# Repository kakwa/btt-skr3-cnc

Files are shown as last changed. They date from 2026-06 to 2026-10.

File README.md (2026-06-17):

# btt-skr3-cnc

Reviving a [Yeti Tool SmartBench](https://www.yetitool.com/) CNC router with new hardware and open-source firmware.

This project replaces pretty much all the sketchy eletronics original electronics with an even sketckier setup.

It keeps the original stepper motors, overal frame, and endstops.

## Project Status

* [done] Pi configuration
* [done] Base grblHAL setup
* [done] Wiring/adapter board
* [in-progress] End stops and safety stop configuration
* [in-progress] Proper enclosure for electronics
* [todo] Spindle control (optional)

## Hardware & Software components

| Component | Details |
|---|---|
| Controller board | [BTT SKR 3 EZ](https://github.com/bigtreetech/SKR-3) |
| Stepper drivers | TMC5160 |
| SBC | [BTT Pi](https://github.com/bigtreetech/BTT-Pi) (or RPi > 3) |
| Firmware | [grblHAL](https://github.com/grblHAL/core/blob/master/README.md) |
| UI & gCode Uploader | [gSender](https://sienci.com/gsender/) |
| Motors Setup | X, Y, Z + ganged X2, Y2 |

## Repository Layout

- `docs/` — project documentation (start here); numbered markdown files covering intro, hardware, install, configuration, troubleshooting, and settings
- `ansible/` — Ansible playbook to provision the BTT Pi (roles: avahi, gsender, grblhal-builder, nginx, ...)
- `grblhal/` — grblHAL firmware as a git submodule (STM32 driver)
- `pcbs/` — KiCad PCB designs for the DB25 breakout boards and adapters
- `cad/` — FreeCAD enclosure and mounting parts
- `tests/` — G-code test files
- `misc/` — utility scripts and raw settings dumps

## Documentation

Project documentation is available in [`docs/`](docs/).

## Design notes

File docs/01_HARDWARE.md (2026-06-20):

# BTT SKR 3 Wiring Guide for grblHAL

## Hardware Overview

- **Board:** [BTT SKR 3 EZ](https://github.com/bigtreetech/SKR-3) (STM32H723VG)
- **Drivers:** [TMC5160T Plus](https://global.bttwiki.com/TMC5160TPlus.html) and/or [TMC5160T Pro](https://global.bttwiki.com/TMC5160T%20Pro%20V1.0.html)
- **Axes:** X (ganged), Y (ganged), Z
- **Total Motors:** 5 (X, X2 on E0, Y, Y2 on E1, Z)

---

## Stepper Controller Allocation

* X          -> X1
* Y          -> Y1
* Z          -> Z
* Extruder 0 -> X2 (ganged)
* Extruder 1 -> Y2 (ganged)

## Breakout Boards

The SmartBench design requires splitting the electronics in two: one part on the top/toolhead, the other below the spoilboard,
with both requiring a wire harness to communicate and transmit power.

The original harness was split in two chains:
* 4 conductors for 24V+230V for powering stuff.
* 13 conductors for the logic and endstops (the loom with the VGA connector).

This split is good: it avoids interference from the power wires.
However, the logic side did not have enough conductors (13) for my setup (3 endstops + 2 SPI TMC drivers).
I even doubt it had enough conductors for the original electronics — the step/dir/enable pins of the two bottom/Y TMC drivers were shared and
the SPI lines were not wired, which seems iffy.

After considering the options (CAN bus, VGA, RJ45 cables, all drivers on top), I decided to replace the logic loom with a DB25 cable.
This connector has enough pins, is common, and should be easy to replace if needed.

I also wanted the setup to be fully reversible with the original electronics — no cutting or clamping of endstop and motor cables.

For all these reasons, I designed two breakout PCBs using KiCad:

* [Bottom breakout PCB](../pcbs/breakout_bottom_dsub25/)
* [Top breakout PCB](../pcbs/breakout_top_dsub25/)

The end result looks like this:

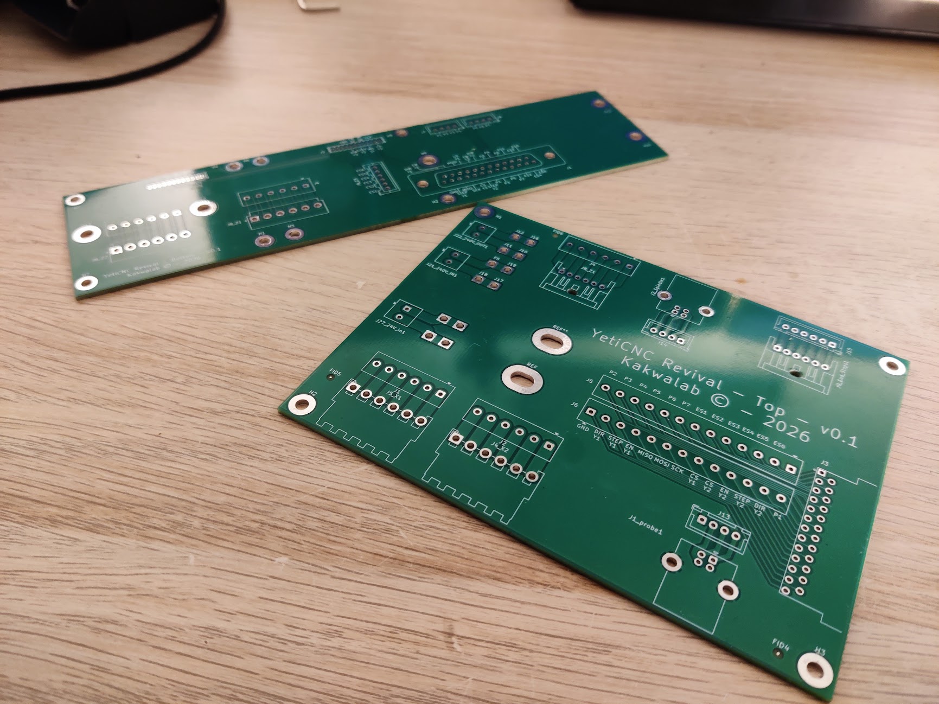
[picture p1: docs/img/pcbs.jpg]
Custom PCBs — top (large) and bottom (small)


These boards interconnect the bottom and top components (via the DB25 cable) and act as adapters between the existing wiring/connectors and what the SKR3 and the TMC5160 drivers expect.
They were also a good opportunity to learn KiCad.

If you are willing to cut some cables, manufacturing these PCBs is not necessary — a pair of DB25 breakout boards with screw terminals can also work:
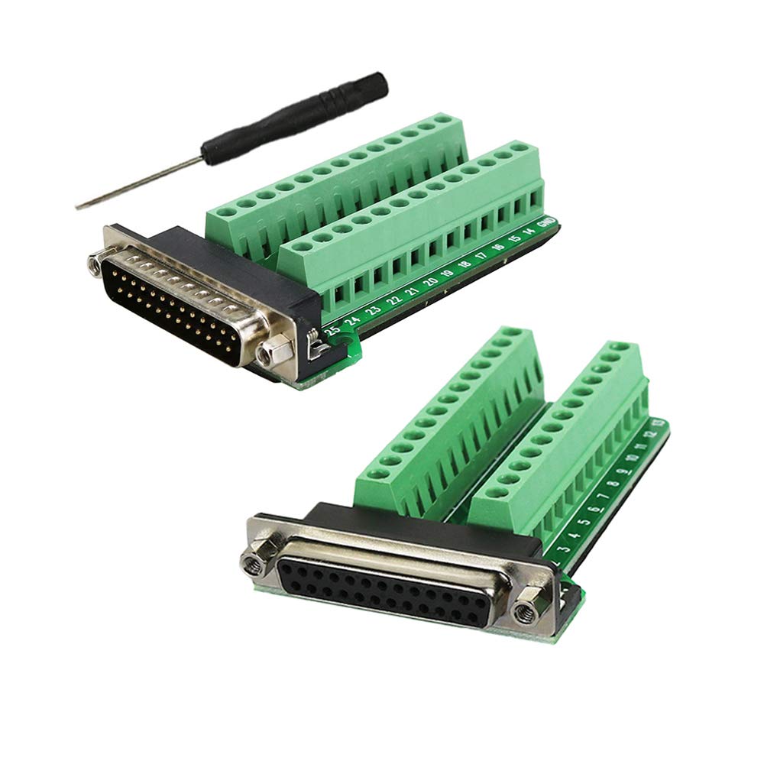
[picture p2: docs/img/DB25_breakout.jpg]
DB25 screw-terminal breakout boards (commercial alternative)


## Stepper Motors & Drivers

Each TMC5160 driver requires at least the following signals routed from the SKR3:

* `STEP`, `DIR`, `EN` — motion control
* `CS` — SPI chip-select (one per driver)
* Shared SPI bus: `MOSI`, `MISO`, `SCK`
* `24V`, `GND` — shared power rails

Here is the non-EZ pinout for reference:

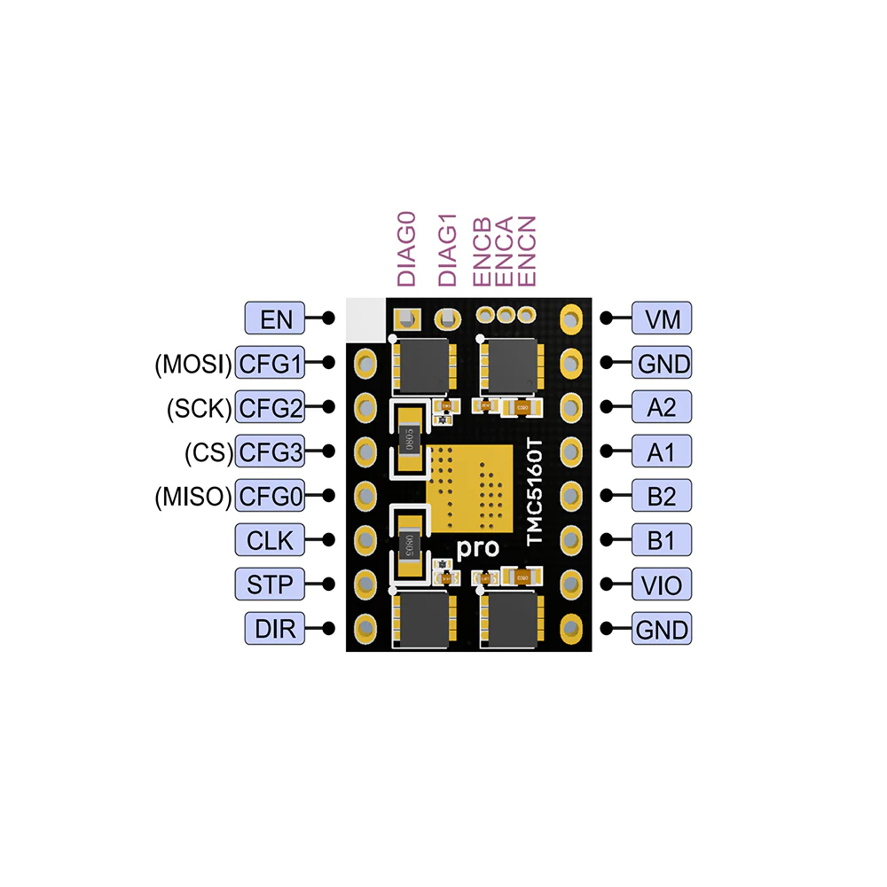
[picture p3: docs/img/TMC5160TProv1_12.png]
Reference Pinout


To connect the Y drivers at the bottom to the SKR 3 board, two adapters are needed.

They can be built easily with a prototype board (strip/breadboard) and some wires:

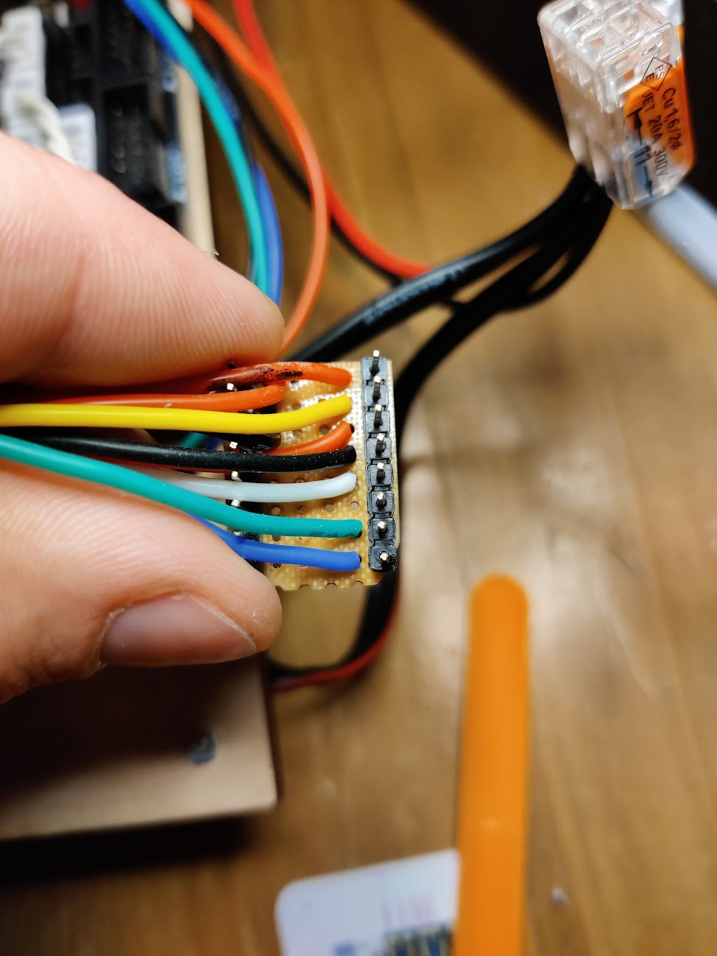
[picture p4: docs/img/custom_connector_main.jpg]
Main motor connector adapter


On the main adapter, everything must be wired:
* SPI bus
* X1-specific pins (DIR, EN, STEP, CS)
* Power & GND

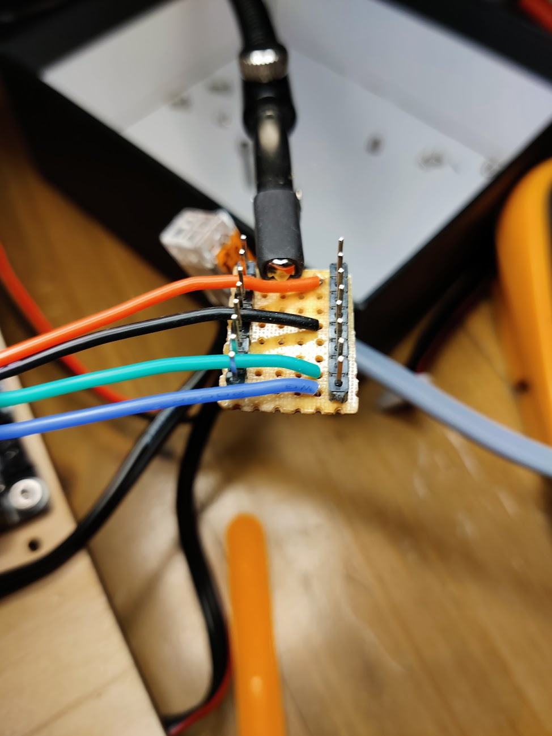
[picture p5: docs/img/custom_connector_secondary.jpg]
Secondary motor connector adapter


On the secondary, only X2-specific signals are needed.

They need to be wired like this:

Stepper Controller Wiring

The end result looks like this:

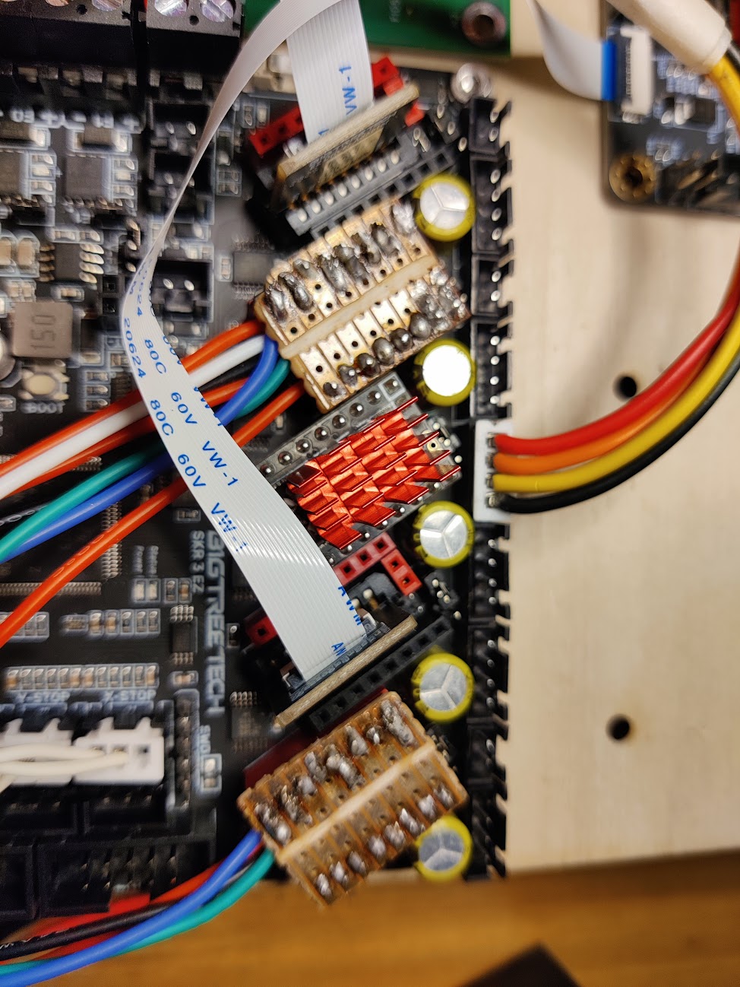
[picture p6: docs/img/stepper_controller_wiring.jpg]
TMC5160 drivers installed


> !Notes
> Most of the more and straight forward usual wiring (PSU, 24V, Stepper loops) is left to the reader.
> However keep in mind the ganded stepper must be mirrored and turning in opposite directions, so if necessary, switch A loop with B loop on X2/Y2.

## Limit Switches, Probe, and Safeties

Port mapping can be found in the [grblHAL board header file for the SKR3](../grblhal/boards/btt_skr_v3.0_map.h).

| Name | GRBLHAL | Pin  | Board label |
|---|---|---|---|
| Z Limit Switch | GPIOC 0 | PC0  | Z- STOP |
| Z Probe | GPIOC 13  | PC13 | Probe |
| Y Limit Switch | GPIOC 3 | PC3  | Y- STOP |
| Y Limit Max Switch | GPIOC 15  | PC15 | PWRDET |
| X Limit Switch | GPIOC 1 | PC1  | X- STOP |
| X Limit Max Switch | GPIOC 2 | PC2  | E0DET |
| Collision Switch/ESTOP | GPIOA 7 | PA7  | EXP2 pin 5  |

Endstop

## Drag Chain

For the DB25 cables (and optionally the power supply for 230V+24V), you can use the drag chain links designed for this build:

* [`chain_link_v2-clip.scad`](../cad/misc/chain_link_v2-clip.scad) — OpenSCAD source for chain links
* [`end1.FCStd`](../cad/misc/end1.FCStd) / [`end2.FCStd`](../cad/misc/end2.FCStd) — FreeCAD models for chain ends

## Spindle

Not handled currently — the spindle runs at fixed speed and is started manually before the job.

## Resulting Jungle

With almost everything connected:

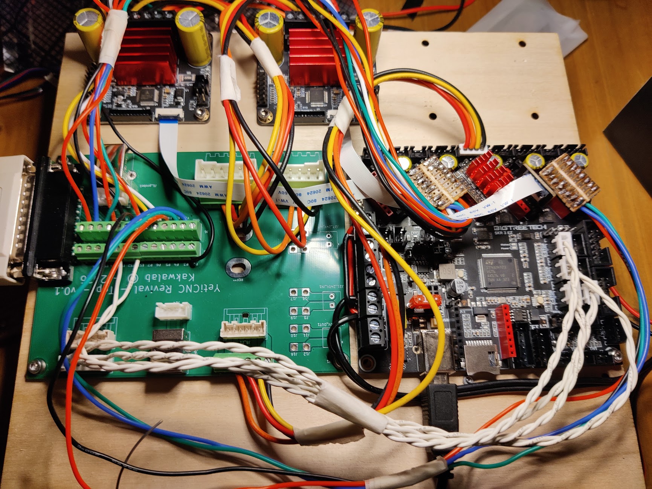
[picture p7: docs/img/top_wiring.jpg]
Top electronics enclosure — top PCB, SKR3, and TMC5160 drivers


The bottom is a bit more manageable:

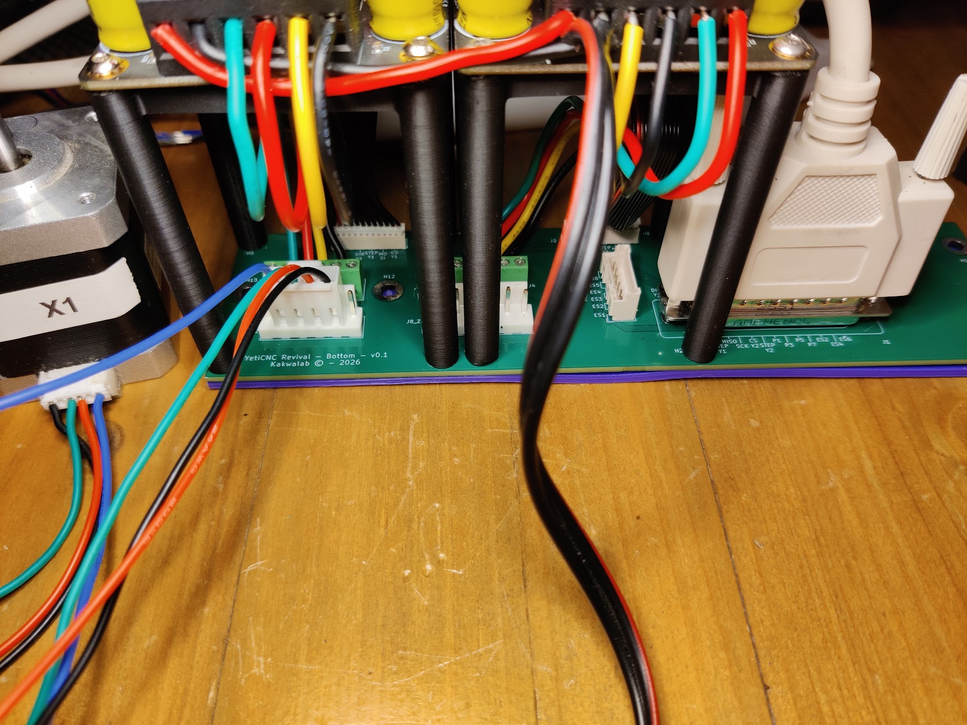
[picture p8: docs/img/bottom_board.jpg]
Bottom breakout board installed, with Y stepper connectors and DB25 cable


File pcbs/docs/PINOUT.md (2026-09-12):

# Pinout

Pin assignment extracted from the schematic. Check strapping/RTC notes before
reassigning pins.

| Refdes | Pin | Name | Net | Notes |
|---|---|---|---|---|
| J1 | 1 | 1 |  | |
| J1 | 2 | 2 |  | |
| J1 | 3 | 3 |  | |
| J1 | 4 | 4 |  | |
| J1 | 5 | 5 |  | |
| J1 | 6 | 6 |  | |
| J1 | 7 | 7 |  | |
| J1 | 8 | 8 |  | |
| J1 | 9 | 9 |  | |
| J1 | 10 | 10 |  | |
| J1 | 11 | 11 |  | |
| J1 | 12 | 12 |  | |
| J1 | 13 | 13 | GND | |
| J1 | 14 | P14 |  | |
| J1 | 15 | P15 |  | |
| J1 | 16 | P16 |  | |
| J1 | 17 | P17 |  | |
| J1 | 18 | P18 |  | |
| J1 | 19 | P19 |  | |
| J1 | 20 | P20 |  | |
| J1 | 21 | P21 |  | |
| J1 | 22 | P22 |  | |
| J1 | 23 | P23 |  | |
| J1 | 24 | P24 |  | |
| J1 | 25 | P25 |  | |
| J2 | 1 | Pin_1 |  | |
| J2 | 2 | Pin_2 |  | |
| J2 | 3 | Pin_3 |  | |
| J2 | 4 | Pin_4 |  | |
| J2 | 5 | Pin_5 |  | |
| J2 | 6 | Pin_6 |  | |
| J2 | 7 | Pin_7 |  | |
| J2 | 8 | Pin_8 |  | |
| J2 | 9 | Pin_9 | GND | |
| J2 | 10 | Pin_10 |  | |
| J2 | 11 | Pin_11 |  | |
| J2 | 12 | Pin_12 | GND | |
| J8_Z1 | 1 | Pin_1 |  | |
| J8_Z1 | 2 | Pin_2 |  | |
| J8_Z1 | 3 | Pin_3 |  | |
| J8_Z1 | 4 | Pin_4 |  | |
| J8_Z1 | 5 | Pin_5 |  | |
| J8_Z1 | 6 | Pin_6 |  | |
| J3 | 1 | Pin_1 |  | |
| J3 | 2 | Pin_2 |  | |
| J3 | 3 | Pin_3 |  | |
| J3 | 4 | Pin_4 |  | |
| J3 | 5 | Pin_5 |  | |
| J3 | 6 | Pin_6 |  | |
| J3 | 7 | Pin_7 |  | |
| J3 | 8 | Pin_8 |  | |
| J3 | 9 | Pin_9 | GND | |
| J3 | 10 | Pin_10 |  | |
| J3 | 11 | Pin_11 |  | |
| J3 | 12 | Pin_12 | GND | |
| J8_Z3 | 1 | Pin_1 |  | |
| J8_Z3 | 2 | Pin_2 |  | |
| J8_Z3 | 3 | Pin_3 |  | |
| J8_Z3 | 4 | Pin_4 |  | |
| J8_Z3 | 5 | Pin_5 |  | |
| J8_Z3 | 6 | Pin_6 |  | |
| J4 | 1 | Pin_1 |  | |
| J4 | 2 | Pin_2 |  | |
| J4 | 3 | Pin_3 |  | |
| J4 | 4 | Pin_4 |  | |
| J4 | 5 | Pin_5 |  | |
| J4 | 6 | Pin_6 |  | |
| J5 | 1 | Pin_1 |  | |
| J5 | 2 | Pin_2 |  | |
| J5 | 3 | Pin_3 |  | |
| J5 | 4 | Pin_4 |  | |
| J5 | 5 | Pin_5 |  | |
| J5 | 6 | Pin_6 |  | |
| J6 | 1 | Pin_1 |  | |
| J6 | 2 | Pin_2 |  | |
| J7 | 1 | Pin_1 |  | |
| J7 | 2 | Pin_2 |  | |
| J7 | 3 | Pin_3 |  | |
| J7 | 4 | Pin_4 |  | |
| J8_Z2 | 1 | Pin_1 |  | |
| J8_Z2 | 2 | Pin_2 |  | |
| J8_Z2 | 3 | Pin_3 |  | |
| J8_Z2 | 4 | Pin_4 |  | |
| J8_Z2 | 5 | Pin_5 |  | |
| J8_Z2 | 6 | Pin_6 |  | |

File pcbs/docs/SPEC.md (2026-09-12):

# bottom_dsub25 — Specification

What the device is, top-level constraints and budgets.

## Budgets

<!-- Add hard budgets here; copperhead treats them as constraints, e.g. -->
<!-- - sleep_current_uA: 25 -->

## Assumptions

<!-- Decisions the agent made without explicit direction are flagged ASSUMED here -->

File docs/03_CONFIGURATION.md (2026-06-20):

# Configuration

## Quick Adjusting

Runtime settings are changed by sending `$N=value` to the board over serial — either via the gSender terminal or `cnc-console`. Each setting is written to flash (NVS) and survives reboots.

See the [grblHAL settings reference](99_SETTINGS.md) for the full list of paramters.

## Making It The Default

Runtime settings persist across power cycles, but a `$RST=*` (factory reset) reverts everything to compile-time defaults. To ensure calibrated values survive a firmware reset:

1. Edit the `grblhal_machine_build_flags` list in `ansible/pi-setup.yml`.
2. Re-run the Ansible playbook with `--tags grblhal` to redeploy `platformio.ini`.
3. Rebuild and reflash the firmware (`skr3-build` then `skr3-flash`).

The corresponding compile-time flags are `-D DEFAULT_X_STEPS_PER_MM=...` etc. They map directly to the `$100`/`$101`/`$102` defaults.

> grblHAL settings are stored in flash. A `$RST=*` is the only way they are lost — a normal reboot preserves them.

## Tuning Points

### Direction

Use `$3` to invert stepper direction for primary axes (bitmask: X=1, Y=2, Z=4).
For ganged axes, `$8` additionally inverts the direction of the second motor (bit 0 = X2, bit 1 = Y2), stacked on top of `$3`.

```bash
$3=0    # no primary axis direction inversion
$8=1    # invert X2 ganged motor only
$8=2    # invert Y2 ganged motor only
$8=3    # invert both ganged motors
```

> The ganged motor (X2/Y2) must turn in the **opposite** direction to its paired primary motor. If the machine racks (X or Y sides move in opposite directions during homing), flip the appropriate bit in `$8`.

### Step <-> Distance Relation

Steps per mm depends on motor full steps/rev (200 for 1.8°), driver microstepping (16 by default), and mechanical pitch.

| Axis | Setting | Nominal (steps/mm) |
|---|---|---|
| X | `$100`  | 80.0 |
| Y | `$101`  | 80.0 |
| Z | `$102`  | 400.0 |
| X2 | `$103`  | 80.0 |
| Y2 | `$104`  | 80.0 |

#### Calibration Protocol

**Step 1 — move a known distance**

Home, then command a large relative move on the axis under test (larger = less measurement error):

> **Warning:** 500 mm is a large move. Jog the axis to roughly the **middle of its travel** before running the move, or it will crash into the far end.

```gcode
$H           ; home all axes
; jog to mid-travel first (e.g. via gSender), then:
G91          ; relative mode
G0 Y140      ; move Y 140 mm  (replace Y with X or Z as needed)
G90          ; back to absolute mode
```

**Step 2 — measure**

Use calipers to measure the actual distance traveled. Note it as `measured`.

**Step 3 — compute and apply**

```
new_steps = current_steps × (commanded / measured)
```

Then set the corrected value:

```gcode
$101=<new_steps>   ; Y axis
```

Repeat from step 1 until measured matches commanded within tolerance.

**Example** — Y commanded 140 mm, measured 210 mm, current `$101=80.0`:

```
new = 80.0 × (140 / 210) = 53.33
```

```gcode
$101=53.33
```

### End Stop

The build flags define the active endstop topology.

**Physical mapping** (from `btt_skr_v3.0_map.h` and build flags):

| Board label | Pin  | grblHAL signal | Purpose |
|---|---|---|---|
| X- STOP | PC1  | `X_LIMIT` | X primary home switch |
| E0DET | PC2  | `M3_LIMIT` | X2 auto-squaring switch |
| Y- STOP | PC3  | `Y_LIMIT` | Y primary home switch |
| PWRDET | PC15 | `M4_LIMIT` | Y2 auto-squaring switch |
| Z- STOP | PC0  | `Z_LIMIT` | Z home switch |
| Probe | PC13 | `PROBE` | Z touch-off / tool length |

**Key homing settings:**

```bash
$22=3     # Enable homing (bit 0) + single-axis $H<X|Y|Z> commands (bit 1)
$23=0     # Homing searches toward negative by default; set bits to reverse per axis
$24=100   # Locate feed rate (mm/min) — slow final approach
$25=1000  # Seek rate (mm/min) — fast initial search
$26=250   # Debounce delay (ms)
$27=5     # Pull-off distance (mm) — must fully clear the switch
$44=4     # Phase 1: home Z first (bitmask: Z=4)
$45=3     # Phase 2: home X and Y together (bitmask: X=1, Y=2)
```

TODO FIXME: currently max and min switch, need to rework that
> Auto-squaring requires **both** limit switches per ganged axis to be functional. If one switch is not triggering, homing will time out or produce a non-zero dual-axis offset in `$170`/`$171`.

### Safety

The collision switch on PA7 (EXP2 pin 5) is active as a **safety door** (`SAFETY_DOOR_ENABLE=1`): triggering it pauses motion and parks the spindle; clearing it allows a resume without a full reset.

Software safety:

```bash
$20=1       # Enable soft limits — requires homing first ($H)
$21=1       # Enable hard limits — alarm on unexpected switch trigger
$130=...    # X max travel (mm) — measure and set
$131=...    # Y max travel (mm)
$132=...    # Z max travel (mm)
```

#### Testing Limit Switches

The `Pn:` field of the `?` status report lists currently triggered inputs. Use this to verify each switch before homing.

1. Open `cnc-console` or the gSender terminal.
2. Send `?` — confirm `Pn:` is empty (no switches active at rest).
3. Manually press each switch one at a time and send `?` again.
4. Confirm the corresponding letter appears in `Pn:`.

| Switch | Board label | Expected `Pn:` letter |
|---|---|---|
| X- STOP | PC1 | `X` |
| Y- STOP | PC3 | `Y` |
| Z- STOP | PC0 | `Z` |
| Probe | PC13 | `P` |

If a switch does not appear, check wiring and the `$5` (invert limit inputs) setting.

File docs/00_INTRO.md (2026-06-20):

# Trying to revive a Yeti Tool SmartBench CNC

## Parts

- **[01_HARDWARE.md](01_HARDWARE.md)** - BTT SKR 3 wiring guide for grblHAL
- **[02_INSTALL.md](02_INSTALL.md)** - Base software setup (Pi, grblHAL build & flash)
- **[03_CONFIGURATION.md](03_CONFIGURATION.md)** - grblHAL configuration
- **[04_TROUBLESHOOTING.md](04_TROUBLESHOOTING.md)** - Troubleshooting and gotchas
- **[90_MISC.md](90_MISC.md)** - Miscellaneous notes
- **[99_SETTINGS.md](99_SETTINGS.md)** - grblHAL settings reference

## Intro

In 2025, I joined a local fablab. If you like building stuff, I would highly recommend it.
These are great places to learn new skills, spend time with really nice people and play
with machines typically out of reach of most.

One of these out-of-reach tools is a SmartBench CNC router by YetiTool. Would love to play with it, but unfortunately, the board burnt out, and it went out of service months before I joined.
To complicate matters, [Yeti Tool went under in 2024](https://find-and-update.company-information.service.gov.uk/company/11310906/insolvency). Not ideal, even if [Trend UK](https://www.trend-eu.com/products/cnc-machines/trend-yeti-cnc-smartbench/trend-yeti-cnc-smartbench) stepped up and started providing spare parts and support.

While I could probably investigate and try fixing the issue, I'm not convinced it's the correct approach:

1. a fix would likely be a fragile bodge just waiting to break again.
2. even if it lasts, it would leave the tool in an unmaintainable state, with no effective software support and partial hardware one.
3. It's less fun

Given I already [built a Voron 0.2](https://www.youtube.com/watch?v=Ej5ZsTKy6t4), it should be easy pizzie lemon squizzy </Dunning-Kruger syndrome>.

## What Are The Options?

Let's limit ourselves to Open Source options, so no [Mach 4](https://www.mach-labs.com/) or similar.

### LinuxCNC + Mesa Hardware

[LinuxCNC](https://linuxcnc.org/) is the gold standard for OSS CNC control: mature, extremely capable, supports virtually any machine topology. But I would not learn that much from it, plus using a PC & Linux for Realtime stuff doesn't seem to fully click.

### FluidNC + ESP32

[FluidNC](https://github.com/bdring/FluidNC) runs on an ESP32 with WiFi built in and YAML-based configuration. It looks really nice and is really promising. The catch is the lack of decent and easily sourceable ESP32 boards. The closest is the [BTT Rodent](https://biqu.equipment/products/bigtreetech-rodent), but it's lacking on the IO and driver department. Plus the drivers are integrated

### grblHAL + STM32

[grblHAL](https://github.com/grblHAL) is GRBL ported to ARM microcontrollers. It keeps GRBL's familiar G-code dialect and adds proper TMC driver support, ganged-axis auto-squaring, and Modbus VFD control. It supports common boards like BTT SKR 3 (STM32H723) I ended up choosing: 5 driver slots, enough GPIO, support of TMC5160.

### Final Choice: grblHAL + BTT SKR 3 + TMC5160 + Pi + gSender

- **BTT SKR 3** (STM32H723VG) running **grblHAL** as the motion controller
- **TMC5160** drivers in UART mode (StallGuard, CoolStep)
- **BTT Pi** running **gSender** as the G-code sender and web UI

For the UI, I picked [gSender](https://sienci.com/gsender/), which is quite nice and has frequent updates.

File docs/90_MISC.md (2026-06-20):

# Misc Pieces of Informations

## Build Work Arounds

**Manual workaround** (if needed):

```bash
# Create symlinks to system toolchain
mkdir -p ~/.platformio/packages/toolchain-gccarmnoneeabi/bin
for f in /usr/bin/arm-none-eabi-*; do
  ln -sf "$f" ~/.platformio/packages/toolchain-gccarmnoneeabi/bin/
done

# Create package.json
cat > ~/.platformio/packages/toolchain-gccarmnoneeabi/package.json << 'EOF'
{
  "name": "toolchain-gccarmnoneeabi",
  "version": "1.70301.190214",
  "description": "System ARM GCC toolchain (symlinked)",
  "keywords": ["toolchain"],
  "license": "GPL-2.0-or-later",
  "system": ["*"]
}
EOF

# Patch platform.json (after first platformio run)
sudo sed -i 's/"version": ">=1.60301.0,<1.80000.0"/"version": "*"/' \
  /root/.platformio/platforms/ststm32/platform.json
```

## Platform.io Packages

For the build, I've created Debian packages for platform.io [here](https://github.com/kakwa/misc-pkg/).

### Manual Flash

#### Step 1: Enter DFU Bootloader Mode

1. **Hold** the BOOT0 button on the SKR3 board
2. **Press and release** the RESET button (while holding BOOT0)
3. **Release** the BOOT0 button

**Verify DFU mode:**
```bash
dfu-util -l
```

You should see:
```
Found DFU: [0483:df11] ver=0200, devnum=X, cfg=1, intf=0, ...
```

#### Step 2: Flash Firmware

```bash
cd /opt/grblhal
dfu-util -a 0 -s 0x08020000 -D .pio/build/btt_skr_30_h723_tmc5160_bl128/firmware.bin
```

**Important:** Use address `0x08020000` (not `0x08000000`) because the SKR3 has a 128KB bootloader.

#### Step 3: Reset Board

Press the **RESET** button on the board to start the firmware.

**Verify it's running:**
```bash
lsusb | grep 0483:5740    # Should show "Virtual COM Port"
ls /dev/ttyACM*           # Serial device (usually /dev/ttyACM0)
```

## Board Configuration

| Setting | Value |
|---|---|
| Board | BTT SKR 3 |
| MCU | STM32H723VG |
| Bootloader | 128KB (factory) |
| Drivers | TMC5160 (UART mode) |
| Flash Address | 0x08020000 |
| PlatformIO Env | `btt_skr_30_h723_tmc5160_bl128` |

## Pi Setup

## Repository Checkout
        
```bash
git clone https://github.com/kakwa/btt-skr3-cnc
cd btt-skr3-cnc/
git submodule update --init --recursive
```     

## Pi Preparation

### SD Card Flashing

Flash the OS to an SD card. Choose one of:

- **Raspberry Pi**: Use Raspberry Pi Imager - https://www.raspberrypi.com/software/
- **BTT Pi** (cheap & 24V, no 5V required): Use Armbian - https://www.armbian.com/bigtreetech-cb1/

### Initial Setup

**Find Pi IP Address via Ethernet (Quick DHCP Server Method):**

If the Pi is not yet on your network, you can set up a quick DHCP server on your local machine to assign it an IP:

```bash
# On your local machine (Linux), install dnsmasq if not already installed
sudo apt install dnsmasq

# List network interfaces and pick your ethernet NIC (often eno1, eth0, enp*s0):
ip addr

# Assign a static address on the link to the Pi (replace eno1 with your interface):
sudo ip addr add 192.168.100.1/24 dev eno1

# Write a minimal dnsmasq config (replace eno1 with your interface):
sudo tee /etc/dnsmasq.conf > /dev/null <<'EOF'
interface=eno1
dhcp-range=192.168.100.50,192.168.100.150,24h
dhcp-option=3
EOF

# Run dnsmasq in foreground
sudo dnsmasq -d -C /etc/dnsmasq.conf

# You should see the IP allocated to the Pi in the logs
# if not, unplug and replug it
```

**Find Pi IP Address via Network Scan:**

```bash
# Scan network for Pi by MAC address prefix
ip neigh | grep -E 'b8:27:eb|dc:a6:32|e4:5f:01|26:a4:ec'
```

**Configure WiFi (if needed):**

```bash
ssh root@<PI_IP>
sudo nmtui
```

**Enable SSH root login:**

```bash
# Enable root login in SSH config
sudo sed -i 's/^#\?PermitRootLogin.*/PermitRootLogin yes/' /etc/ssh/sshd_config
sudo systemctl restart sshd
```

**Setup SSH key for passwordless access:**

```bash
# On your local machine, create SSH key if you don't have one
ssh-keygen
# Copy key to Pi
ssh-copy-id root@<PI_IP>
```

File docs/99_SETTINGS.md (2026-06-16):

# grblHAL Settings Reference

## Table of Contents

- [Motion Control](#motion-control)
- [Spindle Control](#spindle-control)
- [Operational Settings](#operational-settings)
- [Homing & Limits](#homing--limits)
- [Parking](#parking)
- [Axis Configuration](#axis-configuration)
- [Trinamic Driver Settings](#trinamic-driver-settings)
- [Tool Change](#tool-change)
- [I/O Ports](#io-ports)
- [System Settings](#system-settings)

---

## Motion Control

### `$0` — Step pulse time (`µs`, min: 1.5)

Step pulse length in microseconds. Minimum depends on the processor, typically 1–2.5 µs.

> Reduce from the default of 5 when max step rate exceeds ~140 kHz.

---

### `$1` — Step idle delay (`ms`, max: 65535)

Short hold delay when stopping, to let dynamics settle before disabling steppers. Value `255` keeps motors enabled indefinitely.

---

### `$2` — Step pulse invert (`axismask`)

Inverts the step signals (active low).

---

### `$3` — Step direction invert (`axismask`)

Inverts the direction signals (active low).

---

### `$4` — Invert stepper enable output(s) (`axismask`)

Inverts the stepper driver enable signals. Most drivers use active-low enable and require inversion.

> If stepper drivers share the same enable signal, only X is used.

---

### `$29` — Pulse delay (`µs`, max: 20)

Step pulse delay. When set > 0 and < 2, the value is rounded up to 2 µs.

---

### `$37` — Steppers to keep enabled (`axismask`)

Specifies which steppers not to disable when stopped.

---

### `$39` — Enable legacy RT commands (`boolean`)

Enables normal processing of `?`, `!`, and `~` characters when part of a `$`-setting or comment. If disabled, they are added to the input string instead.

---

### `$40` — Limit jog commands (`boolean`)

Limits jog commands to machine workspace for homed axes.

---

### `$680` — Stepper enable delay (`ms`, max: 500)

Delay from stepper enable to first step output. The driver typically adds ~2 ms to this.

---

## Spindle Control

### `$9` — PWM spindle options (`bitfield`)

| Bit | Value | Description |
|-----|---|---|
| 0 | 1 | Enable PWM output |
| 1 | 2 | RPM controls spindle enable signal |
| 2 | 4 | Disable laser mode capability |
| 3 | 8 | Enable ramping |

When *RPM controls spindle enable signal* is set and M3/M4 is active: S0 switches it off, S>0 switches it on.
When *Ramping enable* is set, spin-up/down time is calculated from `$394` and `$539`.

---

### `$16` — Invert spindle signals (`bitfield`)

| Bit | Value | Description |
|-----|---|---|
| 0 | 1 | Spindle enable |
| 1 | 2 | Spindle direction |
| 2 | 4 | PWM |

> **Reboot required** after changing this setting.

---

### `$30` — Maximum spindle speed (`RPM`)

Maximum spindle speed. Can be overridden by spindle plugins.

---

### `$31` — Minimum spindle speed (`RPM`)

Minimum spindle speed. Can be overridden by spindle plugins. When set > 0, `$35` (PWM min value) may need to be adjusted to achieve the configured RPM.

---

### `$32` — Mode of operation

| Value | Mode |
|---|---|
| 0 | Normal |
| 1 | Laser mode |
| 2 | Lathe mode |

- **Laser mode**: consecutive G1/2/3 commands will not halt when spindle speed changes.
- **Lathe mode**: enables G7, G8, G96, and G97.

---

### `$33` — Spindle PWM frequency (`Hz`)

Spindle PWM frequency.

---

### `$34` — Spindle PWM off value (`%`, max: 100)

Spindle PWM off value (duty cycle percentage).

---

### `$35` — Spindle PWM min value (`%`, max: 100)

Spindle PWM minimum value (duty cycle percentage).

---

### `$36` — Spindle PWM max value (`%`, max: 100)

Spindle PWM maximum value (duty cycle percentage).

---

### `$392` — Spindle on delay (`s`, range: 0.5–20)

Delay to allow spindle to spin up after safety door closes or on resume from park.

---

### `$394` — Spindle on delay (`s`, range: 0.5–20)

Delay to allow spindle to spin up. If spindle supports "at speed" detection, this is the timeout before alarm 14 is raised.

---

### `$539` — Spindle off delay (`s`, range: 0.5–20)

Delay to allow spindle to spin down. If spindle supports "at speed" detection, this is the timeout before alarm 14 is raised.

---

## Operational Settings

### `$5` — Invert limit inputs (`axismask`)

Inverts the axis limit input signals.

---

### `$6` — Invert probe inputs (`bitfield`)

| Bit | Value | Description |
|-----|---|---|
| 0 | 1 | Probe |

Inverts the probe input signal(s).

---

### `$8` — Ganged axes direction invert (`bitfield`)

| Bit | Value | Description |
|-----|---|---|
| 0 | 1 | X-Axis |
| 1 | 2 | Y-Axis |

Inverts direction signals for the second motor on ganged axes. Applied in addition to `$3`.

---

### `$10` — Status report options (`bitfield`)

| Bit | Value | Description |
|-----|---|---|
| 0 | 1 | Position in machine coordinate |
| 1 | 2 | Buffer state |
| 2 | 4 | Line numbers |
| 3 | 8 | Feed & speed |
| 4 | 16 | Pin state |
| 5 | 32 | Work coordinate offset |
| 6 | 64 | Overrides |
| 7 | 128 | Probe coordinates |
| 8 | 256 | Buffer sync on WCO change |
| 9 | 512 | Parser state |
| 10  | 1024  | Alarm substatus |
| 11  | 2048  | Run substatus |
| 12  | 4096  | Enable when homing |
| 13  | 8192  | Distance-to-go |

> Parser state is sent separately after the status report and only on changes.
> Run substatus may be used for simple probe protection.

---

### `$11` — Junction deviation (`mm`)

Sets how fast grblHAL travels through consecutive motions. Lower value slows it down.

---

### `$12` — Arc tolerance (`mm`)

Sets the G2/G3 arc tracing accuracy based on radial error.

> Very small values may affect performance.

---

### `$13` — Report in inches (`boolean`)

Enables inch units when returning position and rate values (not settings values).

---

### `$15` — Invert coolant outputs (`bitfield`)

| Bit | Value | Description |
|-----|---|---|
| 0 | 1 | Flood |
| 1 | 2 | Mist |

Inverts coolant and mist signals (active low).

---

### `$18` — Pullup disable limit inputs (`axismask`)

Disables limit signal pullup resistors. Potentially enables pulldown resistors if available.

---

### `$19` — Pullup disable probe inputs (`bitfield`)

| Bit | Value | Description |
|-----|---|---|
| 0 | 1 | Probe |

Disables probe signal pullup resistor(s). Potentially enables pulldown resistor(s) if available.

---

### `$20` — Soft limits enable (`boolean`)

Enables soft limit checks within machine travel. Triggers alarm when exceeded. Requires homing.

---

### `$21` — Hard limits enable (`bitfield`)

| Bit | Value | Description |
|-----|---|---|
| 0 | 1 | Enable |
| 1 | 2 | Strict mode |

When enabled, immediately halts motion and raises an alarm when a limit switch triggers. In strict mode, only homing is possible when a switch is engaged.

---

### `$60` — Restore overrides (`boolean`)

Restores overrides to default values at program end.

---

### `$61` — Safety door options (`bitfield`)

| Bit | Value | Description |
|-----|---|---|
| 1 | 2 | Keep coolant state on door open |

---

### `$62` — Sleep enable (`boolean`)

Enables sleep mode.

---

### `$63` — Feed hold actions (`bitfield`)

| Bit | Value | Description |
|-----|---|---|
| 0 | 1 | Disable laser during hold |
| 1 | 2 | Restore spindle and coolant state on resume |

---

### `$64` — Force init alarm (`boolean`)

Start in alarm mode after a cold reset.

---

### `$65` — Probing options (`bitfield`)

| Bit | Value | Description |
|-----|---|---|
| 0 | 1 | Allow feed override |
| 1 | 2 | Apply soft limits |

Allow feed override during probing and/or limit probing to machine workspace for homed axes.

---

## Homing & Limits

### `$22` — Homing cycle (`bitfield`)

| Bit | Value | Description |
|-----|---|---|
| 0 | 1 | Enable |
| 1 | 2 | Enable single axis commands |
| 2 | 4 | Homing on startup required |
| 3 | 8 | Set machine origin to 0 |
| 4 | 16 | Two switches share one input |
| 5 | 32 | Allow manual |
| 6 | 64 | Override locks |
| 9 | 512 | Per axis feedrates |
| 10  | 1024  | Run startup scripts only on homing completed |

Enables the homing cycle. Requires limit switches on axes to be automatically homed.

- *Enable single axis commands*: allows `$H<axis>` commands for individual axis homing.
- *Allow manual*: axes not auto-homed may be homed manually via `$H` or `$H<axis>`.
- *Override locks*: allows a soft reset to disable "Homing on startup required".

---

### `$23` — Homing direction invert (`axismask`)

Homing searches in the positive direction by default. Set an axis bit to search in the negative direction.

---

### `$24` — Homing locate feed rate (`mm/min`)

Feed rate to slowly engage the limit switch to determine its location accurately.

---

### `$25` — Homing search seek rate (`mm/min`)

Seek rate to quickly find the limit switch before the slower locating phase.

---

### `$26` — Homing switch debounce delay (`ms`)

Short delay between homing cycle phases to let the switch debounce.

---

### `$27` — Homing switch pull-off distance (`mm`)

Retract distance after triggering the switch to disengage it. Homing will fail if the switch isn't cleared.

---

### `$43` — Homing passes (range: 1–128)

Number of homing passes.

---

### `$44` — Axes homing, first phase (`axismask`)

Axes to home in the first phase.

---

### `$45` — Axes homing, second phase (`axismask`)

Axes to home in the second phase.

---

### `$46` — Axes homing, third phase (`axismask`)

Axes to home in the third phase.

---

### `$338` — Trinamic driver (`axismask`)

Enable SPI or UART controlled Trinamic drivers for axes.

---

### `$339` — Sensorless homing (`axismask`)

Enable sensorless homing for axes. Requires SPI or UART controlled Trinamic drivers.

---

## Parking

### `$41` — Parking cycle (`bitfield`)

| Bit | Value | Description |
|-----|---|---|
| 0 | 1 | Enable |
| 1 | 2 | Deactivate upon init |
| 2 | 4 | Enable parking override control|

Enables parking cycle. Requires parking axis to be homed.

---

### `$42` — Parking axis

| Value | Axis |
|---|---|
| 0 | X |
| 1 | Y |
| 2 | Z |

Defines which axis performs the parking motion.

---

### `$56` — Parking pull-out distance (`mm`)

Spindle pull-out and plunge distance (incremental).

---

### `$57` — Parking pull-out rate (`mm/min`)

Spindle pull-out/plunge slow feed rate.

---

### `$58` — Parking target (`mm`, min: -100000)

Parking axis target in machine coordinates `[-max_travel, 0]`.

---

### `$59` — Parking fast rate (`mm/min`)

Parking fast rate to target after pull-out.

---

## Axis Configuration

### Steps per mm

| Setting | Axis |
|---|---|
| `$100`  | X-axis travel resolution (`step/mm`) |
| `$101`  | Y-axis travel resolution (`step/mm`) |
| `$102`  | Z-axis travel resolution (`step/mm`) |

---

### Maximum rate

| Setting | Axis |
|---|---|
| `$110`  | X-axis maximum rate (`mm/min`) |
| `$111`  | Y-axis maximum rate (`mm/min`) |
| `$112`  | Z-axis maximum rate (`mm/min`) |

Used as G0 rapid rate.

---

### Acceleration

| Setting | Axis |
|---|---|
| `$120`  | X-axis acceleration (`mm/sec²`) |
| `$121`  | Y-axis acceleration (`mm/sec²`) |
| `$122`  | Z-axis acceleration (`mm/sec²`) |

Used for motion planning to avoid exceeding motor torque and losing steps.

---

### Maximum travel

| Setting | Axis |
|---|---|
| `$130`  | X-axis maximum travel (`mm`) |
| `$131`  | Y-axis maximum travel (`mm`) |
| `$132`  | Z-axis maximum travel (`mm`) |

Maximum axis travel distance from homing switch. Determines valid machine space for soft limits and homing search distances.

---

### Dual axis offset

| Setting | Axis | Range |
|---|---|---|
| `$170`  | X-axis dual axis offset (`mm`) | -10 – 10  |
| `$171`  | Y-axis dual axis offset (`mm`) | -10 – 10  |
| `$172`  | Z-axis dual axis offset (`mm`) | -10 – 10  |

Offset between sides to compensate for homing switch inaccuracies.

---

## Trinamic Driver Settings

### Motor current (RMS)

| Setting | Axis | Range |
|---|---|---|
| `$140`  | X-axis motor current (`mA`) | 0–3045  |
| `$141`  | Y-axis motor current (`mA`) | 0–3045  |
| `$142`  | Z-axis motor current (`mA`) | 0–3045  |

---

### Microsteps

| Setting | Axis | Range  |
|---|---|---|
| `$150`  | X-axis microsteps (`steps`)  | 1–256  |
| `$151`  | Y-axis microsteps (`steps`)  | 1–256  |
| `$152`  | Z-axis microsteps (`steps`)  | 1–256  |

Microsteps per full step.

---

### Hold current

| Setting | Axis | Range  |
|---|---|---|
| `$210`  | X-axis hold current (`%`)  | 5–100  |
| `$211`  | Y-axis hold current (`%`)  | 5–100  |
| `$212`  | Z-axis hold current (`%`)  | 5–100  |

Motor current at standstill as a percentage of full current.

---

### StallGuard2 — Fast threshold (seek phase)

| Setting | Axis | Range |
|---|---|---|
| `$200`  | X-axis StallGuard2 fast threshold | -64–63  |
| `$201`  | Y-axis StallGuard2 fast threshold | -64–63  |
| `$202`  | Z-axis StallGuard2 fast threshold | -64–63  |

StallGuard threshold for the fast (seek) homing phase.

---

### StallGuard2 — Slow threshold (feed phase)

| Setting | Axis | Range |
|---|---|---|
| `$220`  | X-axis StallGuard2 slow threshold | -64–63  |
| `$221`  | Y-axis StallGuard2 slow threshold | -64–63  |
| `$222`  | Z-axis StallGuard2 slow threshold | -64–63  |

StallGuard threshold for the slow (feed) homing phase.

---

## Tool Change

### `$341` — Tool change mode

| Value | Mode |
|---|---|
| 0 | Normal |
| 1 | Manual touch off |
| 2 | Manual touch off @ G59.3 |
| 3 | Automatic touch off @ G59.3 |
| 4 | Ignore M6 |

- **Normal**: allows jogging for manual touch off; set new position manually.
- **Manual touch off**: rapids to tool change position; use jogging or `$TPW` for touch off.
- **Manual touch off @ G59.3**: rapids to tool change position, then to G59.3 for manual touch off.
- **Automatic touch off @ G59.3**: rapids to tool change position, then to G59.3 for automatic touch off.

---

### `$342` — Tool change probing distance (`mm`)

Maximum probing distance for automatic or `$TPW` touch off.

---

### `$343` — Tool change locate feed rate (`mm/min`)

Feed rate to slowly engage the tool change sensor to determine offset accurately.

---

### `$344` — Tool change search seek rate (`mm/min`)

Seek rate to quickly find the tool change sensor before the slower locating phase.

---

### `$345` — Tool change probe pull-off rate (`mm/min`)

Pull-off rate for the retract move before the slower locating phase.

---

### `$346` — Tool change options (`bitfield`)

| Bit | Value | Description |
|-----|---|---|
| 0 | 1 | Restore position after M6 |
| 1 | 2 | Change tool at G30 |
| 2 | 4 | Fast probe pull off |

- *Restore position after M6*: moves spindle so the tool tip returns to pre-M6 position; otherwise moves only to Z home.
- *Change tool at G30*: rapids to G30 position via tool axis home (requires homed axes).
- *Fast probe pull off*: uses G38.4-style probing for faster touch off.

---

### `$347` — Dual axis length fail (`%`, range: 0–100)

Dual axis length fail threshold as a percentage of axis max travel.

---

### `$348` — Dual axis length fail min (`mm`)

Dual axis length fail minimum distance.

---

### `$349` — Dual axis length fail max (`mm`)

Dual axis length fail maximum distance.

---

## I/O Ports

### `$370` — Invert I/O port inputs (`bitfield`)

| Bit | Value | Description |
|-----|---|---|
| 0 | 1 | Aux 0 |
| 2 | 4 | Aux 2 |
| 3 | 8 | Aux 3 |
| 4 | 16 | Aux 4 |

---

### `$372` — Invert I/O port outputs (`bitfield`)

| Bit | Value | Description |
|-----|---|---|
| 5 | 32 | Aux 5 |
| 6 | 64 | Aux 6 |

---

## System Settings

### `$28` — G73 Retract distance (`mm`)

G73 retract distance for chip-breaking drilling.

---

### `$384` — Disable G92 persistence (`boolean`)

Disables save/restore of G92 offset to non-volatile storage (NVS).

---

### `$393` — Coolant on delay (`s`, range: 0.5–20)

Delay to allow coolant to restart after safety door closes or on resume from park.

---

### `$398` — Planner buffer blocks (range: 30–1000)

Number of blocks in the planner buffer.

> **Reboot required** after changing this setting.

---

### `$481` — Autoreport interval (`ms`, range: 100–1000)

Interval at which the real-time report is sent. Set to `0` to disable.

> **Reboot required** after changing this setting.

---

### `$485` — Keep tool number over reboot (`boolean`)

Retains the current tool number across reboots.

---

### `$486` — Lock coordinate systems (`bitfield`)

| Bit | Value | Description |
|-----|---|---|
| 0 | 1 | G59.1 |
| 1 | 2 | G59.2 |
| 2 | 4 | G59.3 |

Locks coordinate systems against accidental changes.

---

### `$650` — File system options (`bitfield`)

| Bit | Value | Description |
|-----|---|---|
| 0 | 1 | Auto mount SD card |
| 2 | 4 | Hierarchical listing |

Auto mount SD card on startup.

---

### `$673` — Coolant on delay (`s`, range: 0.5–20)

Delay to allow coolant to start (0 or 0.5–20 s).

---

### `$676` — Reset actions (`bitfield`)

| Bit | Value | Description |
|-----|---|---|
| 0 | 1 | Clear homed status if position was lost |
| 1 | 2 | Clear offsets (except G92) |
| 2 | 4 | Clear rapids override |
| 3 | 8 | Clear feed override |

Controls actions taken on a soft reset.

---

### `$700` — Subroutine options (`bitfield`)

| Bit | Value | Description |
|-----|---|---|
| 0 | 1 | Prescan for internal M98 subroutines |

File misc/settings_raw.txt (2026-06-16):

> $HELP Settings

$0: Step pulse time in microseconds, min: 1.5

Step pulse length in microseconds.
Minimum depends on the processor and is typically in the range of 1 - 2.5.

The length has to be reduced from the default value of 5 when max. step rate exceed approximately 140 kHz.

$1: Step idle delay in milliseconds, max: 65535

Sets a short hold delay when stopping to let dynamics settle before disabling steppers. Value 255 keeps motors enabled.

$2: Step pulse invert as axismask

Inverts the step signals (active low).

$3: Step direction invert as axismask

Inverts the direction signals (active low).

$4: Invert stepper enable output(s) as axismask

Inverts the stepper driver enable signals. Most drivers uses active low enable requiring inversion.

NOTE: If the stepper drivers shares the same enable signal only X is used.

$5: Invert limit inputs as axismask

Inverts the axis limit input signals.

$6: Invert probe inputs as bitfield:
    0 - Probe (1)

Inverts the probe input signal(s).

$8: Ganged axes direction invert as bitfield:
    0 - X-Axis (1)
    1 - Y-Axis (2)

Inverts the direction signals for the second motor used for ganged axes.

NOTE: This inversion will be applied in addition to the inversion from setting $3.

$9: PWM spindle options as bitfield where setting bit 0 enables the rest:
    0 - Enable (1)
    1 - RPM controls spindle enable signal (2)
    2 - Disable laser mode capability (4)
    3 - Enable ramping (8)

Enable controls PWM output availability.
When `RPM controls spindle enable signal` is checked and M3 or M4 is active S0 switches it off and S > 0 switches it on.
When 'Ramping enable' is checked spin up and spin down time is calculated from $394 and $539 respectively.

$10: Status report options as bitfield:
    0 - Position in machine coordinate (1)
    1 - Buffer state (2)
    2 - Line numbers (4)
    3 - Feed & speed (8)
    4 - Pin state (16)
    5 - Work coordinate offset (32)
    6 - Overrides (64)
    7 - Probe coordinates (128)
    8 - Buffer sync on WCO change (256)
    9 - Parser state (512)
    10 - Alarm substatus (1024)
    11 - Run substatus (2048)
    12 - Enable when homing (4096)
    13 - Distance-to-go (8192)

Specifies optional data included in status reports and if report is sent when homing.
If Run substatus is enabled it may be used for simple probe protection.

NOTE: Parser state will be sent separately after the status report and only on changes.

$11: Junction deviation in mm

Sets how fast grblHAL travels through consecutive motions. Lower value slows it down.

$12: Arc tolerance in mm

Sets the G2 and G3 arc tracing accuracy based on radial error. Beware: A very small value may effect performance.

$13: Report in inches as boolean

Enables inch units when returning any position and rate value that is not a settings value.

$15: Invert coolant outputs as bitfield:
    0 - Flood (1)
    1 - Mist (2)

Inverts the coolant and mist signals (active low).

$16: Invert spindle signals as bitfield:
    0 - Spindle enable (1)
    1 - Spindle direction (2)
    2 - PWM (4)

Reboot required.

Inverts the spindle on, counterclockwise and PWM signals (active low).

NOTE: A hard reset of the controller is required after changing this setting.

$18: Pullup disable limit inputs as axismask

Disable the limit signals pullup resistors. Potentially enables pulldown resistors if available.

$19: Pullup disable probe inputs as bitfield:
    0 - Probe (1)

Disable the probe signal pullup resistor(s). Potentially enables pulldown resistor(s) if available.

$20: Soft limits enable as boolean

Enables soft limits checks within machine travel and sets alarm when exceeded. Requires homing.

$21: Hard limits enable as bitfield where setting bit 0 enables the rest:
    0 - Enable (1)
    1 - Strict mode (2)

When enabled immediately halts motion and throws an alarm when a limit switch is triggered. In strict mode only homing is possible when a switch is engaged.

$22: Homing cycle as bitfield where setting bit 0 enables the rest:
    0 - Enable (1)
    1 - Enable single axis commands (2)
    2 - Homing on startup required (4)
    3 - Set machine origin to 0 (8)
    4 - Two switches shares one input (16)
    5 - Allow manual (32)
    6 - Override locks (64)
    9 - Per axis feedrates (512)
    10 - Run startup scripts only on homing completed (1024)

Enables homing cycle. Requires limit switches on axes to be automatically homed.

When `Enable single axis commands` is checked, single axis homing can be performed by $H<axis letter> commands.

When `Allow manual` is checked, axes not homed automatically may be homed manually by $H or $H<axis letter> commands.

`Override locks` is for allowing a soft reset to disable `Homing on startup required`.

$23: Homing direction invert as axismask

Homing searches for a switch in the positive direction. Set axis bit to search in negative direction.

$24: Homing locate feed rate in mm/min

Feed rate to slowly engage limit switch to determine its location accurately.

$25: Homing search seek rate in mm/min

Seek rate to quickly find the limit switch before the slower locating phase.

$26: Homing switch debounce delay in milliseconds

Sets a short delay between phases of homing cycle to let a switch debounce.

$27: Homing switch pull-off distance in mm

Retract distance after triggering switch to disengage it. Homing will fail if switch isn't cleared.

$28: G73 Retract distance in mm

G73 retract distance (for chip breaking drilling).

$29: Pulse delay in microseconds, max: 20

Step pulse delay.

When set > 0 and less than 2 the value is rounded up to 2 microseconds.

$30: Maximum spindle speed in RPM

Maximum spindle speed, can be overridden by spindle plugins.

$31: Minimum spindle speed in RPM

Minimum spindle speed, can be overridden by spindle plugins.

When set > 0 $35 (PWM min value) may have to be set to get the configured RPM.

$32: Mode of operation:
    0 - Normal
    1 - Laser mode
    2 - Lathe mode

Laser mode: consecutive G1/2/3 commands will not halt when spindle speed is changed.
Lathe mode: allows use of G7, G8, G96 and G97.

$33: Spindle PWM frequency in Hz

Spindle PWM frequency.

$34: Spindle PWM off value in percent, max: 100

Spindle PWM off value in percent (duty cycle).

$35: Spindle PWM min value in percent, max: 100

Spindle PWM min value in percent (duty cycle).

$36: Spindle PWM max value in percent, max: 100

Spindle PWM max value in percent (duty cycle).

$37: Steppers to keep enabled as axismask

Specifies which steppers not to disable when stopped.

$39: Enable legacy RT commands as boolean

Enables "normal" processing of ?, ! and ~ characters when part of $-setting or comment. If disabled then they are added to the input string instead.

$40: Limit jog commands as boolean

Limit jog commands to machine workspace for homed axes.

$41: Parking cycle as bitfield where setting bit 0 enables the rest:
    0 - Enable (1)
    1 - Deactivate upon init (2)
    2 - Enable parking override control (4)

Enables parking cycle, requires parking axis homed.

$42: Parking axis:
    0 - X
    1 - Y
    2 - Z

Define which axis that performs the parking motion.

$43: Homing passes, range: 1 - 128

Number of homing passes. Minimum 1, maximum 128.

$44: Axes homing, first phase as axismask

Axes to home in first phase.

$45: Axes homing, second phase as axismask

Axes to home in second phase.

$46: Axes homing, third phase as axismask

Axes to home in third phase.

$56: Parking pull-out distance in mm

Spindle pull-out and plunge distance in mm.Incremental distance.

$57: Parking pull-out rate in mm/min

Spindle pull-out/plunge slow feed rate in mm/min.

$58: Parking target in mm, min: -100000

Parking axis target. In mm, as machine coordinate [-max_travel, 0].

$59: Parking fast rate in mm/min

Parking fast rate to target after pull-out in mm/min.

$60: Restore overrides as boolean

Restore overrides to default values at program end.

$61: Safety door options as bitfield:
    1 - Keep coolant state on door open (2)

Ignore when idle: disregard door signal in IDLE state to allow jogging etc. Available when controller has door input.
Keep coolant state on open: do not turn off coolant if on.

$62: Sleep enable as boolean

Enable sleep mode.

$63: Feed hold actions as bitfield:
    0 - Disable laser during hold (1)
    1 - Restore spindle and coolant state on resume (2)

Actions taken during feed hold and on resume from feed hold.

$64: Force init alarm as boolean

Start in alarm mode after a cold reset.

$65: Probing options as bitfield:
    0 - Allow feed override (1)
    1 - Apply soft limits (2)

Allow feed override during probing and/or limit probing commands to machine workspace for homed axes.

$100: X-axis travel resolution in step/mm

Travel resolution in steps per millimeter.

$101: Y-axis travel resolution in step/mm

Travel resolution in steps per millimeter.

$102: Z-axis travel resolution in step/mm

Travel resolution in steps per millimeter.

$110: X-axis maximum rate in mm/min

Maximum rate. Used as G0 rapid rate.

$111: Y-axis maximum rate in mm/min

Maximum rate. Used as G0 rapid rate.

$112: Z-axis maximum rate in mm/min

Maximum rate. Used as G0 rapid rate.

$120: X-axis acceleration in mm/sec^2

Acceleration. Used for motion planning to not exceed motor torque and lose steps.

$121: Y-axis acceleration in mm/sec^2

Acceleration. Used for motion planning to not exceed motor torque and lose steps.

$122: Z-axis acceleration in mm/sec^2

Acceleration. Used for motion planning to not exceed motor torque and lose steps.

$130: X-axis maximum travel in mm

Maximum axis travel distance from homing switch. Determines valid machine space for soft-limits and homing search distances.

$131: Y-axis maximum travel in mm

Maximum axis travel distance from homing switch. Determines valid machine space for soft-limits and homing search distances.

$132: Z-axis maximum travel in mm

Maximum axis travel distance from homing switch. Determines valid machine space for soft-limits and homing search distances.

$140: X-axis motor current in mA, range: 0 - 3045

Motor current in mA (RMS).

$141: Y-axis motor current in mA, range: 0 - 3045

Motor current in mA (RMS).

$142: Z-axis motor current in mA, range: 0 - 3045

Motor current in mA (RMS).

$150: X-axis microsteps in steps, range: 1 - 256

Microsteps per fullstep.

$151: Y-axis microsteps in steps, range: 1 - 256

Microsteps per fullstep.

$152: Z-axis microsteps in steps, range: 1 - 256

Microsteps per fullstep.

$170: X-axis dual axis offset in mm, range: -10 - 10

Offset between sides to compensate for homing switches inaccuracies.

$171: Y-axis dual axis offset in mm, range: -10 - 10

Offset between sides to compensate for homing switches inaccuracies.

$172: Z-axis dual axis offset in mm, range: -10 - 10

Offset between sides to compensate for homing switches inaccuracies.

$200: X-axis StallGuard2 fast threshold, range: -64 - 63

StallGuard threshold for fast (seek) homing phase.

$201: Y-axis StallGuard2 fast threshold, range: -64 - 63

StallGuard threshold for fast (seek) homing phase.

$202: Z-axis StallGuard2 fast threshold, range: -64 - 63

StallGuard threshold for fast (seek) homing phase.

$210: X-axis hold current in %, range: 5 - 100

Motor current at standstill as a percentage of full current.

$211: Y-axis hold current in %, range: 5 - 100

Motor current at standstill as a percentage of full current.

$212: Z-axis hold current in %, range: 5 - 100

Motor current at standstill as a percentage of full current.

$220: X-axis stallGuard2 slow threshold, range: -64 - 63

StallGuard threshold for slow (feed) homing phase.

$221: Y-axis stallGuard2 slow threshold, range: -64 - 63

StallGuard threshold for slow (feed) homing phase.

$222: Z-axis stallGuard2 slow threshold, range: -64 - 63

StallGuard threshold for slow (feed) homing phase.

$338: Trinamic driver as axismask

Enable SPI or UART controlled Trinamic drivers for axes.

$339: Sensorless homing as axismask

Enable sensorless homing for axes. Requires SPI or UART controlled Trinamic drivers.

$341: Tool change mode:
    0 - Normal
    1 - Manual touch off
    2 - Manual touch off @ G59.3
    3 - Automatic touch off @ G59.3
    4 - Ignore M6

Normal: allows jogging for manual touch off. Set new position manually.

Manual touch off: rapids to tool change position, use jogging or $TPW for touch off.

Manual touch off @ G59.3: rapids to tool change position, after change to G59.3 position for manual touch off. Use jogging or $TPW for touch off.

Automatic touch off @ G59.3: rapids to tool change position, after change to G59.3 position for automatic touch off.

Depending on settings the tool (controlled point) will be moved back to the to original position after touch off. "tool change position" is either tool axis home, G59.3 or G30 position depending on settings.

$342: Tool change probing distance in mm

Maximum probing distance for automatic or $TPW touch off.

$343: Tool change locate feed rate in mm/min

Feed rate to slowly engage tool change sensor to determine the tool offset accurately.

$344: Tool change search seek rate in mm/min

Seek rate to quickly find the tool change sensor before the slower locating phase.

$345: Tool change probe pull-off rate in mm/min

Pull-off rate for the retract move before the slower locating phase.

$346: Tool change options as bitfield:
    0 - Restore position after M6 (1)
    1 - Change tool at G30 (2)
    2 - Fast probe pull off (4)

Restore position after M6: when set the spindle is moved so that the controlled point (tool tip) is the same as before the M6 command,if not the spindle is only moved to the Z home position.

Change tool at G30: when set rapids to the G30 position via tool axis home. Requires axes to be homed.

Fast probe pulloff: use G38.4 style probing for faster touch off.

$347: Dual axis length fail in percent, range: 0 - 100

Dual axis length fail in percent of axis max travel.

$348: Dual axis length fail min in mm

Dual axis length fail minimum distance.

$349: Dual axis length fail max in mm

Dual axis length fail maximum distance.

$370: Invert I/O Port inputs as bitfield:
    0 - Aux 0 (1)
    2 - Aux 2 (4)
    3 - Aux 3 (8)
    4 - Aux 4 (16)

Invert IOPort inputs.

$372: Invert I/O Port outputs as bitfield:
    5 - Aux 5 (32)
    6 - Aux 6 (64)

Invert IOPort output.

$384: Disable G92 persistence as boolean

Disables save/restore of G92 offset to non-volatile storage (NVS).

$392: Spindle on delay in s, range: 0.5 - 20

Delay to allow spindle to spin up after safety door is closed or on resume from park.

$393: Coolant on delay in s, range: 0.5 - 20

Delay to allow coolant to restart after safety door is closed or on resume from park.

$394: Spindle on delay in s, range: 0.5 - 20

Delay to allow spindle to spin up. 0 or 0.5 - 20s
If spindle supports "at speed" functionality it is the time to wait before alarm 14 is raised.

$398: Planner buffer blocks, range: 30 - 1000, reboot required

Number of blocks in the planner buffer.

NOTE: A hard reset of the controller is required after changing this setting.

$481: Autoreport interval in ms, range: 100 - 1000, reboot required

Interval the real time report will be sent, set to 0 to disable.

NOTE: A hard reset of the controller is required after changing this setting.

$485: Keep tool number over reboot as boolean

$486: Lock coordinate systems as bitfield:
    0 - G59.1 (1)
    1 - G59.2 (2)
    2 - G59.3 (4)

Lock coordinate systems against accidental changes.

$539: Spindle off delay in s, range: 0.5 - 20

Delay to allow spindle to spin down. 0 or 0.5 - 20s
If spindle supports "at speed" functionality it is the time to wait before alarm 14 is raised.

$650: File systems options as bitfield:
    0 - Auto mount SD card (1)
    2 - Hierarchical listing (4)

Auto mount SD card on startup.

$673: Coolant on delay in s, range: 0.5 - 20

Delay to allow coolant to start. 0 or 0.5 - 20s.

$676: Reset actions as bitfield:
    0 - Clear homed status if position was lost (1)
    1 - Clear offsets (except G92) (2)
    2 - Clear rapids override (4)
    3 - Clear feed override (8)

Controls actions taken on a soft reset.

$680: Stepper enable delay in ms, max: 500

Delay from stepper enable to first step output. The driver typically adds ~2ms to this.

$700: Subroutine options as bitfield:
    0 - Prescan for internal M98 subroutines (1)
ok

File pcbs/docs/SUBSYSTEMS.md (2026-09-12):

# Subsystems

Per-sheet values and reasoning (regulator, charger, RF, ...).

## Sheet /

- FID1: Fiducial
- FID2: Fiducial
- FID3: Fiducial
- H1: MountingHole
- H2: MountingHole
- H3: MountingHole
- H4: MountingHole
- H5: MountingHole
- H6: MountingHole
- H7: MountingHole
- H8: MountingHole
- H9: MountingHole
- H10: MountingHole
- H11: MountingHole
- H12: MountingHole
- H13: MountingHole
- J1: DB25_Pins
- J2: Conn_01x12
- J3: Conn_01x12
- J4: Screw_Terminal_01x06
- J5: Screw_Terminal_01x06
- J6: Conn_01x02
- J7: Conn_01x04
- J8_Z1: Conn_01x06_Pin
- J8_Z2: Conn_01x06_Pin
- J8_Z3: Conn_01x06_Pin

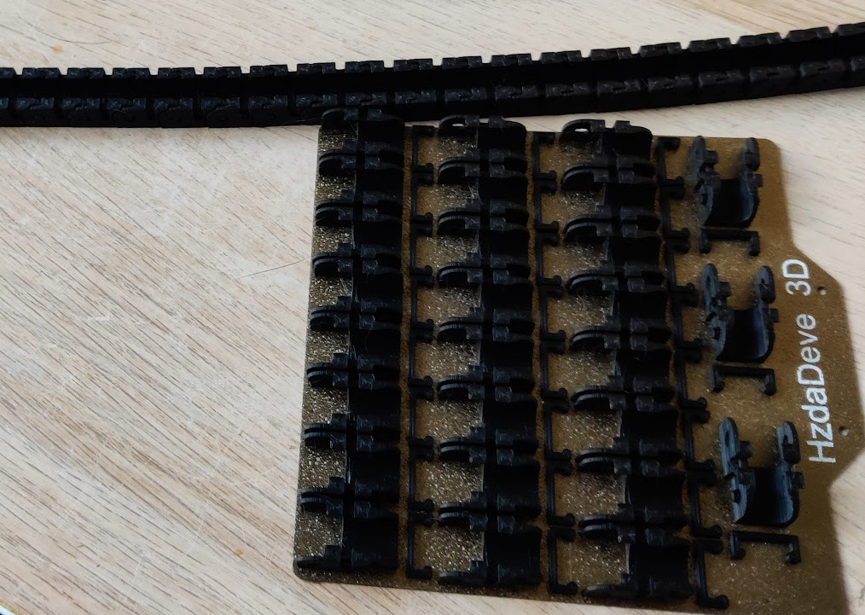
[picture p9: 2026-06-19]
docs/img/drag_chain.jpg

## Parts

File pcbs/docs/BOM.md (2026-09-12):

# Bill of Materials

Every part: refdes, MPN, value, package, and WHY it was chosen. MPNs the agent
introduces without a datasheet check are flagged UNVERIFIED.

Value holds the component value only ("4.7uF", "1M", "500mAh Li-Po") — the
schematic stage draws it as the symbol's Value field, so a description there
collides with neighbouring symbols and fails the legibility gate. Prose belongs
in Rationale. One row per refdes; a grouped row ("C5-C8") matches no symbol.

| Refdes | Value | Footprint | MPN | Rationale |
|---|---|---|---|---|
| FID1 | Fiducial |  | UNVERIFIED | extracted from schematic by copperhead init |
| FID2 | Fiducial |  | UNVERIFIED | extracted from schematic by copperhead init |
| FID3 | Fiducial |  | UNVERIFIED | extracted from schematic by copperhead init |
| H1 | MountingHole | MountingHole:MountingHole_3.2mm_M3_DIN965_Pad_TopBottom | UNVERIFIED | extracted from schematic by copperhead init |
| H2 | MountingHole | MountingHole:MountingHole_3.2mm_M3_DIN965_Pad_TopBottom | UNVERIFIED | extracted from schematic by copperhead init |
| H3 | MountingHole | MountingHole:MountingHole_3.2mm_M3_DIN965_Pad_TopBottom | UNVERIFIED | extracted from schematic by copperhead init |
| H4 | MountingHole | MountingHole:MountingHole_3.2mm_M3_DIN965_Pad_TopBottom | UNVERIFIED | extracted from schematic by copperhead init |
| H5 | MountingHole | MountingHole:MountingHole_3.2mm_M3_DIN965_Pad_TopBottom | UNVERIFIED | extracted from schematic by copperhead init |
| H6 | MountingHole | MountingHole:MountingHole_3.2mm_M3_DIN965_Pad_TopBottom | UNVERIFIED | extracted from schematic by copperhead init |
| H7 | MountingHole | MountingHole:MountingHole_3.2mm_M3_DIN965_Pad_TopBottom | UNVERIFIED | extracted from schematic by copperhead init |
| H8 | MountingHole | MountingHole:MountingHole_3.2mm_M3_DIN965_Pad_TopBottom | UNVERIFIED | extracted from schematic by copperhead init |
| H9 | MountingHole | MountingHole:MountingHole_4.3mm_M4_DIN965_Pad_TopBottom | UNVERIFIED | extracted from schematic by copperhead init |
| H10 | MountingHole | MountingHole:MountingHole_4.3mm_M4_DIN965_Pad_TopBottom | UNVERIFIED | extracted from schematic by copperhead init |
| H11 | MountingHole | MountingHole:MountingHole_4.3mm_M4_DIN965_Pad_TopBottom | UNVERIFIED | extracted from schematic by copperhead init |
| H12 | MountingHole | MountingHole:MountingHole_4.3mm_M4_DIN965_Pad_TopBottom | UNVERIFIED | extracted from schematic by copperhead init |
| H13 | MountingHole | MountingHole:MountingHole_4.3mm_M4_DIN965_Pad_TopBottom | UNVERIFIED | extracted from schematic by copperhead init |
| J1 | DB25_Pins | Connector_Dsub:DSUB-25_Pins_Vertical_P2.77x2.84mm_MountingHoles | UNVERIFIED | extracted from schematic by copperhead init |
| J2 | Conn_01x12 | Connector_JST:JST_ZH_B12B-ZR_1x12_P1.50mm_Vertical | UNVERIFIED | extracted from schematic by copperhead init |
| J3 | Conn_01x12 | Connector_JST:JST_ZH_B12B-ZR_1x12_P1.50mm_Vertical | UNVERIFIED | extracted from schematic by copperhead init |
| J4 | Screw_Terminal_01x06 | TerminalBlock_Phoenix:TerminalBlock_Phoenix_MKDS-1-6-3.81_1x06_P3.81mm_Horizontal | UNVERIFIED | extracted from schematic by copperhead init |
| J5 | Screw_Terminal_01x06 | TerminalBlock_Phoenix:TerminalBlock_Phoenix_MKDS-1-6-3.81_1x06_P3.81mm_Horizontal | UNVERIFIED | extracted from schematic by copperhead init |
| J6 | Conn_01x02 | Connector_JST:JST_XH_B2B-XH-A_1x02_P2.50mm_Vertical | UNVERIFIED | extracted from schematic by copperhead init |
| J7 | Conn_01x04 | Connector_JST:JST_XH_B4B-XH-A_1x04_P2.50mm_Vertical | UNVERIFIED | extracted from schematic by copperhead init |
| J8_Z1 | Conn_01x06_Pin | Connector_JST:JST_VH_B6P-VH_1x06_P3.96mm_Vertical | UNVERIFIED | extracted from schematic by copperhead init |
| J8_Z2 | Conn_01x06_Pin | Connector_JST:JST_VH_B6P-VH_1x06_P3.96mm_Vertical | UNVERIFIED | extracted from schematic by copperhead init |
| J8_Z3 | Conn_01x06_Pin | Connector_JST:JST_XA_B06B-XASK-1_1x06_P2.50mm_Vertical | UNVERIFIED | extracted from schematic by copperhead init |

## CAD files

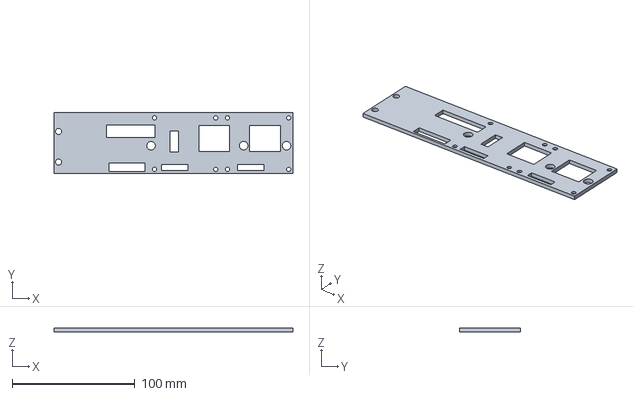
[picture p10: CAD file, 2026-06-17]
cad/bottom_enclosure/backplate_bottom.FCStd
195.0 x 50.0 x 3.00 mm

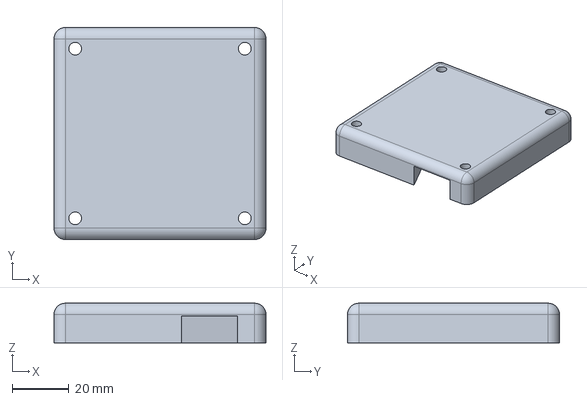
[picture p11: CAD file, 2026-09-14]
cad/estop_bracket/estop_bracket.FCStd
75.0 x 75.0 x 14.0 mm

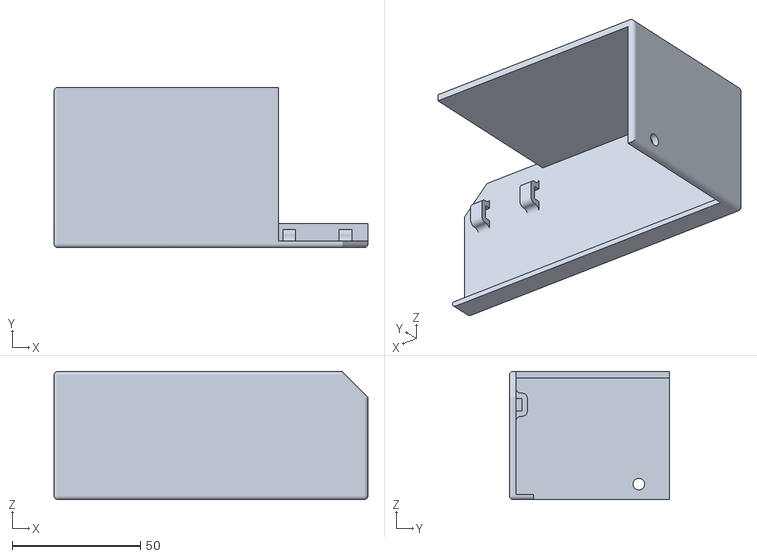
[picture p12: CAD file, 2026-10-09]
cad/misc/cap-BodyPad004.stl
122.5 x 62.5 x 50.0

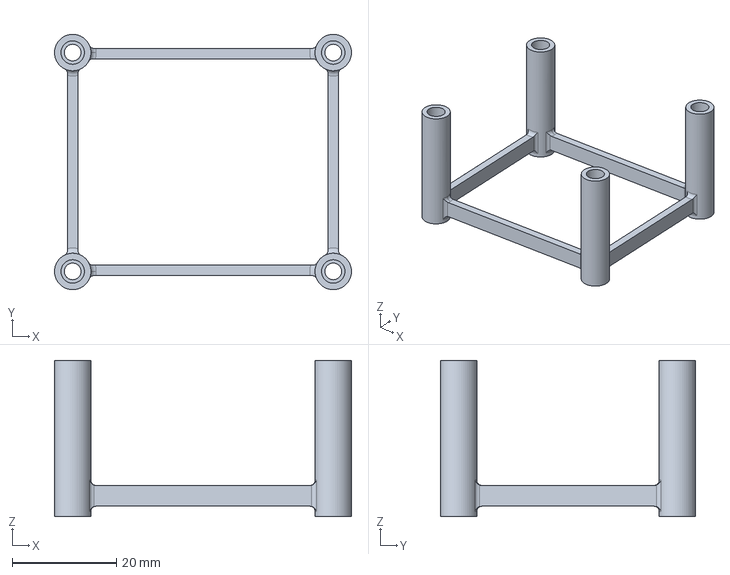
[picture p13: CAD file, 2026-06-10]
cad/bottom_enclosure/standoff_driver_bottom.FCStd
57.0 x 49.0 x 30.0 mm

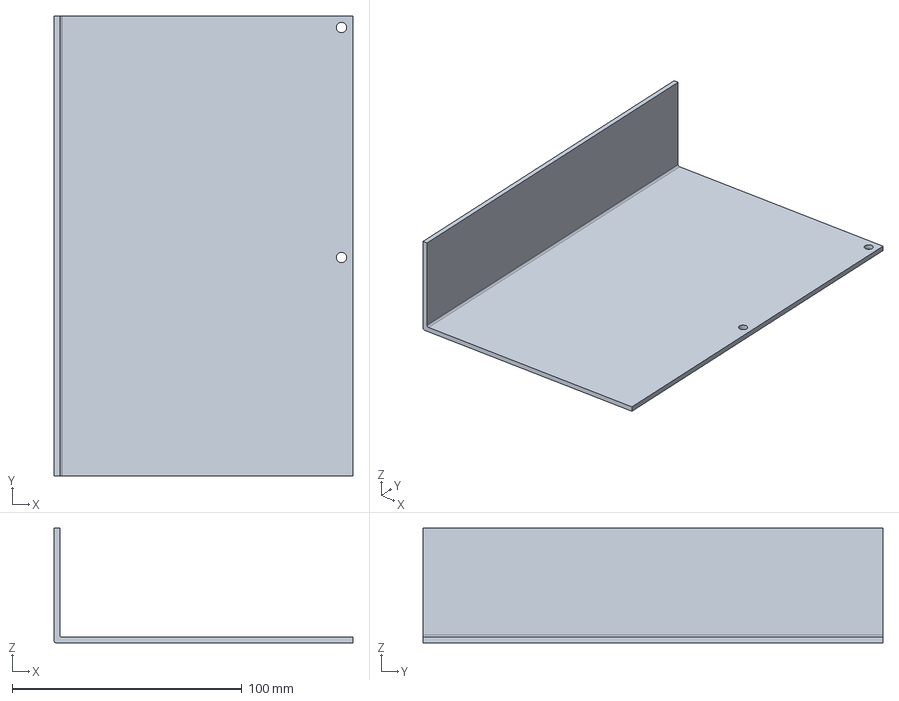
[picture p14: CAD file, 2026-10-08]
cad/misc/cover.FCStd
130.0 x 200.0 x 50.0 mm

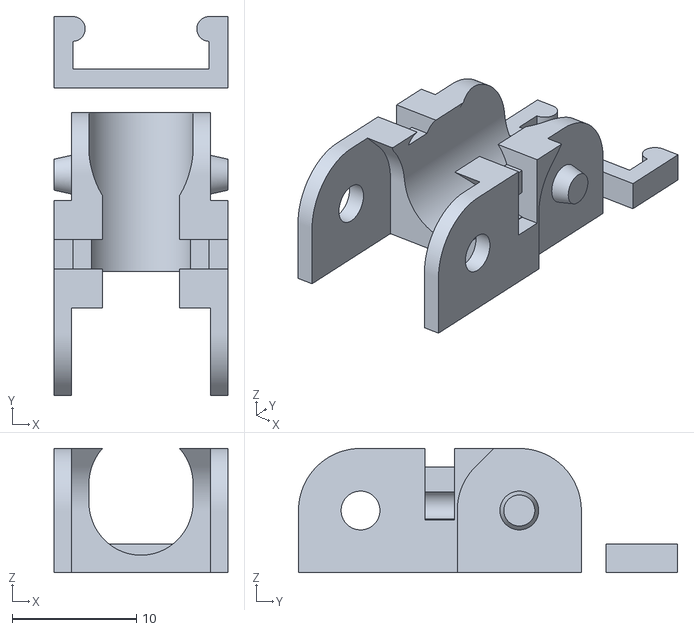
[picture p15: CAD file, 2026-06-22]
cad/misc/chain_link_no_leg.stl
14.0 x 30.5 x 10.0

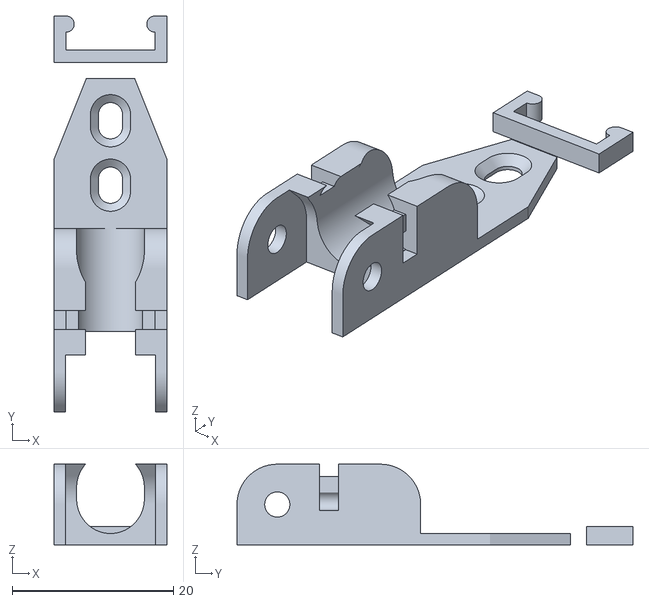
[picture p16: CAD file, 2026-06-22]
cad/misc/chain_link_outter_leg.stl
14.0 x 49.1 x 10.0

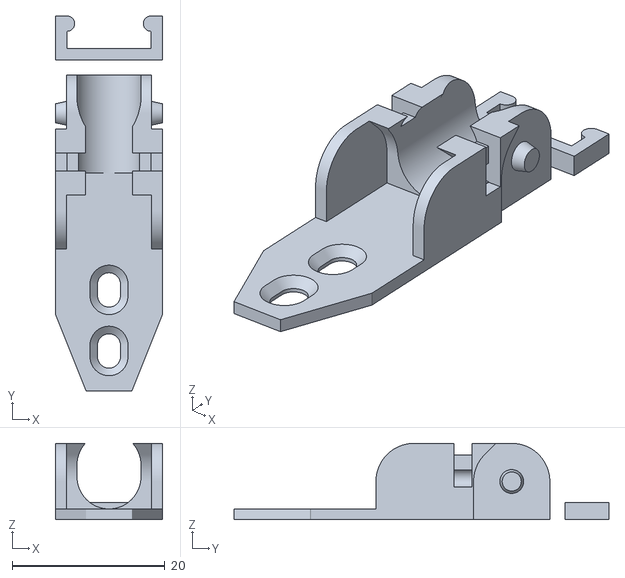
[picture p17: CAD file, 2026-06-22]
cad/misc/chain_link_inner_leg.stl
14.0 x 49.1 x 10.0

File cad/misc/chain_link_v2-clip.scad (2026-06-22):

/*
Original Code by Joerg Scheuermann: https://www.thingiverse.com/Joerg
Original on Thingiverse: https://www.thingiverse.com/thing:8239

Clip module, Toothpick diameter Variable,
OpenSCAD/Thingiverse Customizer optimization,
Multicolor Modifier Block and extra comments
added by Gasol1n (Christian Riedl): https://www.gasol1n.com/
https://www.thingiverse.com/Gasolin

Licensed under CC BY-SA 3.0
https://creativecommons.org/licenses/by-sa/3.0/
*/

/* [Size] */
// Width of the Chain Link
width= 14;
// Length of the Chain Link
length=17;
// Height of the Chain Link
height=10;

/* [Hidden] */
// Hard cap on articulation angle to prevent links from locking or colliding
max_angle = 50;

/* [Angles] */
// Max angle the chain can bend downward (toward the base)
under_angle=0; // [50]
// Max angle the chain can bend upward (away from the base)
over_angle=45; // [50]

/* [Variant] */
// true: pivot pins point inward (female outer shell); false: pins point outward (male outer shell)
// Must alternate or match between linked pairs — mixing produces the male/female joint
inner_axis=0; // [1:true, 0:false]

// true: print the snap-in clip beside the link; false: only print the link (no clip printed)
clip=1; // [1:true, 0:false]

// true: add end chain attaching leg on the outter side; false: no leg
end_leg_outter=0; // [1:true, 0:false]
// true: add end chain attaching leg on the inner side; false: no leg
end_leg_inner=0; // [1:true, 0:false]

/* [Legs] */
// Length of the end attaching legs
leg_length=30; // [5:5:100]

/* [Further Settings] */
// Extra clearance on mating surfaces to account for FDM dimensional variance
tolerance = 0.001;

/* [Further Settings] */
// Extra clip clearance on mating surfaces to account for FDM dimensional variance
clip_tolerance = 0.1;

// Builds the outer shell of one link: a rectangular body with rounded cylindrical ends.
// The angular wedge cuts at each end shape the bending pocket so adjacent links can
// rotate up to `angle` degrees without the shells clashing.
module outline(width, length, height, radius, l1, angle)
{
    y_ofs = l1 / 2;
    t     = radius / 2;

    difference() {
        union() {
            translate([0, 0, height/2])    cube([width,l1,height], true);
            translate([0, -y_ofs, radius]) rotate([0, 90, 0]) cylinder(width, r = radius, center = true, $fn=200);
            translate([0,  y_ofs, radius]) rotate([0, 90, 0]) cylinder(width, r = radius, center = true, $fn=200);
            translate([0, -y_ofs, radius]) rotate([angle,     0, 0]) translate([0, -t, -t]) cube([width,radius,radius], true);
            translate([0,  y_ofs, radius]) rotate([360-angle, 0, 0]) translate([0,  t, -t]) cube([width,radius,radius], true);
        }
        // Trim the bottom flat so the printed part sits flush on the bed
        translate([0, 0, -(t/2)]) cube([width,length,t], true);
    }
}

// Tapered pivot pin — narrower at the tip so it self-aligns when pressing links together.
// The taper also provides a slight press-fit retention in the matching axis_hole.
module axis(x_ofs, y_ofs, z_ofs, length, radius)
{
    rad = (radius * 0.25);
    translate([x_ofs,y_ofs,z_ofs]) rotate([0, 90, 0]) cylinder(length+tolerance, r1 = rad*1.25, r2 = rad, center = true, $fn=200);
}

// Matching tapered socket for the pivot pin. Scaled up by tolerance so the pin slides in
// without friction but cannot rattle sideways during articulation.
module axis_hole(x_ofs, y_ofs, z_ofs, length, radius)
{
    rad = (radius * 0.25) * 1.25;
    translate([x_ofs,y_ofs,z_ofs]) rotate([0, 90, 0]) cylinder(length+tolerance, r1 = rad+tolerance, r2 = rad, center = true, $fn=200);
}

// Cuts the outer ear on one side of one link end.
// The ear receives (or provides) the pivot pin that joins two links.
// `inner_axis` flips whether this ear carries the pin or the socket — links must be
// printed with opposite inner_axis values to mate correctly.
module outcut0(width, radius, h1, thick, angle, inner_axis)
{
    w = (width - thick)/2;
    t = thick + tolerance/2;

    translate([w, 0, 0]) union() {
        difference() {
            union() {
                translate([0,0,h1/2]) cube([t,radius*2, h1], true);
                // Angular wedge mirrors the outline's sweep pocket on the ear geometry
                translate([0,0,h1]) rotate([angle, 0, 0]) translate([0,radius/2,0]) cube([t,radius,radius*2], true);
                translate([0,0,h1]) rotate([0, 90, 0]) cylinder(t, r = radius, center = true, $fn=200);
                if (inner_axis) {
                    axis_hole(-(1.5*w), tolerance/2, h1,w,radius);
                }
            }
            if (!inner_axis) {
                axis(-(tolerance)/2, tolerance/2, h1,thick,radius);
            }
        }
    }
}
// Mirrors outcut0 to produce symmetric ears on both sides of the link end.
module outcut(width, radius, l1, h1, thick, angle, inner_axis)
{
    translate([0,l1/2,0]) union() {
        outcut0(width, radius, h1, thick, angle, inner_axis);
        mirror([1,0,0]) outcut0(width, radius, h1, thick, angle, inner_axis);
    }
}

// Cuts the inner fork at the opposite end of the link — the fork cradles the ears of
// the next link and carries the opposite half of the pivot joint (pin or socket,
// whichever outcut didn't provide).
module incut(width, radius, l1, h1, thick, angle, inner_axis, end_leg_inner=0)
{
    width2 = width - 2*(thick-tolerance);

    translate([0,-(l1/2),h1]) difference() {
        union() {
            translate([0,0,-(h1/2)]) cube([width2,radius*2,h1], true);
            translate([0,0,0]) rotate([180-angle,0,0]) translate([0,radius/2,0]) cube([width2, radius, radius*2], true);
            translate([0,0,0]) rotate([0, 90, 0]) cylinder(width2, r = radius, center = true, $fn=200);
            if (!inner_axis && !end_leg_inner) {
                axis_hole((width-thick)/2+tolerance, -(tolerance/2), 0,thick,radius);
                mirror([1,0,0]) axis_hole((width-thick)/2+tolerance, -(tolerance/2), 0,thick,radius);
            }
        }
        if (inner_axis) {
            axis(-((width2-thick)/2), -(tolerance/2), 0,thick,radius);
            mirror([1,0,0]) axis(-((width2-thick)/2), -(tolerance/2), 0,thick,radius);
        }
    }
}

// Cross-section profile of the cable channel — open C-profile (two cylinders + connecting slab).
module middle_0(length, radius, thick)
{
    rotate([90, 90, 0]) cylinder(length, r = radius, center = true, $fn=200);
    translate([0,0,thick]) rotate([90, 90, 0]) cylinder(length, r = radius, center = true, $fn=200);
    translate([0,0,thick/2]) cube([2*radius,length,thick], true);
}

// Carves out the hollow cable channel running through the full length of the link.
// The channel is split into three segments (centre + two angled halves) and each half
// is swept through the articulation angle so the bore stays clear at maximum bend —
// preventing cables from being pinched at the joint.
module middle(width, radius, length, height, l1, h1, thick, over, under, inner_axis)
{
    l = length;
    th = max(thick,thick * height/width);
    h = height - th;
    w = width - 4*thick;
    r = h / 2;
    scale(v=[w/h,1,1]) translate(v = [0,0,r+th]) union() {
        translate([0,h1,0]) middle_0(l, r, th);
        translate([0,(l1/2)+0.1,0]) {
            difference() {
                rotate([over,0,0]) union() {
                    translate([0, l/4, 0]) middle_0(l/2, r, th);
                    translate([0, l/4,-r]) cube([2*r,l/2,2*r], true);
                }
                translate([0, l/4,-r]) cube([2*r,l/2,2*r], true);
            }
            difference() {
                rotate([-under,0,0]) union() {
                    translate([0, l/4, 0]) middle_0(l/2, r, th);
                    translate([0, l/4,r]) cube([2*r,l/2,2*r], true);
                }
                translate([0, l/4,r]) cube([2*r,l/2,2*r], true);
            }
        }
    }
}
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

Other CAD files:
cad/misc/cap.FCStd

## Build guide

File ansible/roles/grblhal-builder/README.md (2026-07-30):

# grblhal-builder Role

Ansible role to set up grblHAL build environment and deploy custom configuration for BTT SKR3 board with TMC5160 drivers.

## Features

- Installs ARM GCC toolchain and PlatformIO
- Deploys grblHAL sources from local repository
- Injects a custom `[env:kwcnc_yeti]` PlatformIO build environment with machine-specific build flags
- Creates helper scripts for building and flashing firmware

## Configuration

The role configures the BTT SKR3 board with:

- **5 TMC5160 stepper drivers** in SPI mode
- **Ganged X and Y axes** (auto-squaring disabled by default — see [Ganged Axes Configuration](#ganged-axes-configuration))
- **3 primary axes** (X, Y, Z) + 2 ganged motors (X2, Y2)
- Custom build identifier with timestamp
- USB serial communication
- SD card support
- Probe support

## Variables

See `defaults/main.yml` for all available variables:

### Key Variables

- `grblhal_board`: Target board (default: `BTT_SKR_3_EZ`)
- `grblhal_mcu`: Target MCU (default: `STM32H7xx`)
- `grblhal_platformio_env`: PlatformIO environment (default: `btt_skr_30_h723_tmc5160_bl128`)
- `grblhal_source_dir`: Source directory on target (default: `/opt/grblhal`)

### Feature Toggles

- `grblhal_install_build_tools`: Install build toolchain (default: `true`)
- `grblhal_install_flash_tools`: Install DFU flash tools (default: `true`)
- `grblhal_deploy_sources`: Deploy grblHAL sources (default: `true`)

## Files

### Templates

- `templates/platformio_kwcnc_yeti.ini.j2`: Renders the `[env:kwcnc_yeti]` PlatformIO environment block, layered on top of the upstream `btt_skr_30_h723_tmc5160_bl128` environment (board, linker script, `lib_deps`), with `grblhal_machine_build_flags` appended as extra `build_flags`. This rendered block is injected into `{{ grblhal_source_dir }}/platformio.ini` via a `blockinfile` task (see `tasks/main.yml`).
- `templates/skr3-build.sh.j2`: Build script helper
- `templates/skr3-flash.sh.j2`: Flash script helper (interactive DFU mode)

## Usage

### Basic Playbook

```yaml
- hosts: cnc_controller
  roles:
    - grblhal-builder
```

### With Custom Variables

```yaml
- hosts: cnc_controller
  roles:
    - role: grblhal-builder
      vars:
        grblhal_source_dir: /home/user/grblhal
        grblhal_update_platformio: true
```

### Building Firmware

After deployment, build firmware on the target:

```bash
# Using helper script
skr3-build

# Or directly with PlatformIO
cd /opt/grblhal
platformio run -e btt_skr_30_h723_tmc5160_bl128
```

### Flashing Firmware

```bash
# Interactive DFU flash (guides through button presses)
skr3-flash

# Or specify firmware file
skr3-flash /path/to/firmware.bin
```

## Ganged Axes Configuration

### What are Ganged Axes?

Ganged axes use **two motors for a single axis** to provide:
- More power/torque
- Better rigidity
- Auto-squaring capability (using dual limit switches)

### This Configuration

- **X axis**: 2 motors (X + X2 on M3/E0 stepper)
- **Y axis**: 2 motors (Y + Y2 on M4/E1 stepper)
- **Z axis**: 1 motor
- **Total**: 5 TMC5160 drivers

## TMC5160 Motor Current Configuration

### Key Settings (PlatformIO build flags in `ansible/pi-setup.yml`)

Motor current intensity is controlled by these `grblhal_machine_build_flags` entries (rendered as `-D` defines):

```yaml
- "-D DEFAULT_X_CURRENT=1000.0f"  # mA RMS (run current)
- "-D DEFAULT_Y_CURRENT=1000.0f"
- "-D DEFAULT_Z_CURRENT=1000.0f"
- "-D DEFAULT_A_CURRENT=1000.0f"  # X2 ganged motor
- "-D DEFAULT_B_CURRENT=1000.0f"  # Y2 ganged motor
- "-D TRINAMIC_R_SENSE=75"        # Sense resistor (milliohms)
```

Not currently set (grblHAL defaults apply unless added to `grblhal_machine_build_flags`): `TMC_X_HOLD_CURRENT_PCT`, `TRINAMIC_DEFAULT_MICROSTEPS`, `TMC_STEALTHCHOP`.

### How to Choose Motor Current

1. **Check motor datasheet** for rated current (usually in Amps)
2. **Set to ~70-85% of rated current** for good balance of torque and heat
3. **TMC5160 maximum**: 3000mA (3A) per driver
4. **Start conservatively**: 1000mA, increase if needed

**Examples:**
- **NEMA 17** (1.5A rated): Set to 1000-1200mA
- **NEMA 23** (2.0A rated): Set to 1400-1700mA
- **NEMA 23** (2.8A rated): Set to 2000-2400mA
- **NEMA 34** (3.0A rated): Set to 2100-2550mA

### Tuning Motor Current

**Too Low Current:**
- Motors skip steps under load
- Lost position / weak cutting
- Machine stalls easily

**Too High Current:**
- Motors overheat
- Drivers overheat (check heatsinks!)
- Wasted power
- Potential damage

**Testing:**
1. Start with calculated value (70% of rated)
2. Run test moves with typical cutting forces
3. Check motor temperature after 30 minutes
   - Warm to touch = OK (~40-50°C)
   - Too hot to touch = Reduce current (~60°C+)
4. Increase current if losing steps
5. Add heatsinks if drivers get hot

### Hold Current

`TMC_X_HOLD_CURRENT_PCT` reduces power when motors are stationary:
- **50%**: Good balance (default)
- **30%**: More power saving, may allow movement on vertical axes
- **70%**: More holding torque, more heat

### StealthChop vs SpreadCycle

**SpreadCycle** (`TMC_STEALTHCHOP 0`) - Default, recommended for CNC:
- ✅ High torque at all speeds
- ✅ Better for cutting operations
- ❌ Audible motor hum

**StealthChop** (`TMC_STEALTHCHOP 1`) - Quiet mode:
- ✅ Nearly silent operation
- ❌ Reduced torque at higher speeds
- ⚠️ Not recommended for CNC (use for 3D printers)

### Microstepping

`TRINAMIC_DEFAULT_MICROSTEPS` - Steps per full step:
- **16** (default): Best balance for CNC (smooth + good torque)
- **32/64**: Smoother motion, slightly less torque
- **256**: Maximum smoothness, lowest torque per microstep
- **8**: More torque, less smooth (rarely needed)

### Runtime Configuration

After flashing, motor current can be tuned via grblHAL settings without rebuilding firmware. These settings are stored in EEPROM and persist across reboots.

### Important Notes

1. **N_AXIS remains 3**: grblHAL reports `[AXS:3:XYZ]` because ganged motors are not separate axes
2. **Settings**: Look for `$103`, `$104` (steps/mm for X2, Y2), `$113`, `$114` (max rate)
3. **Auto-squaring**: Requires dual limit switches per ganged axis

## Configuration Architecture

### Primary Configuration: PlatformIO build flags

All feature settings are passed as compiler `-D` build flags, not via `Inc/my_machine.h`. The base `btt_skr_30_h723_tmc5160_bl128` environment (defined upstream in `grblhal/platformio.ini`) already sets `OVERRIDE_MY_MACHINE`, so `my_machine.h` is ignored regardless — the flags below are the single source of truth:

```yaml
grblhal_machine_build_flags:
  - "-D X_GANGED=1"            # Enable X axis ganging
  - "-D X_AUTO_SQUARE=0"       # X auto-squaring disabled
  - "-D Y_GANGED=1"            # Enable Y axis ganging
  - "-D Y_AUTO_SQUARE=0"       # Y auto-squaring disabled
  - "-D TRINAMIC_ENABLE=5160"  # TMC5160 support
  - "-D TRINAMIC_SPI_ENABLE=1" # Use SPI mode
  # ...see ansible/pi-setup.yml for the full list (currents, steps/mm, limits, etc.)
```

These are defined in `ansible/pi-setup.yml` (`grblhal_machine_build_flags` var) and rendered into `[env:kwcnc_yeti]` by `templates/platformio_kwcnc_yeti.ini.j2`.

### PlatformIO Build Settings

The rendered `[env:kwcnc_yeti]` block inherits board, linker script (128KB bootloader), and `lib_deps`/`lib_extra_dirs` from the upstream `btt_skr_30_h723_tmc5160_bl128` environment, and appends `grblhal_machine_build_flags` on top.

## Troubleshooting

### Build Issues

**Problem**: Ganged axes not working after build
**Solution**: Ensure `grblhal_machine_build_flags` in `ansible/pi-setup.yml` still contains `X_GANGED=1`/`Y_GANGED=1`, and re-run the playbook so the `[env:kwcnc_yeti]` block in `platformio.ini` is refreshed.

**Problem**: Build fails with "BTT SKR-3 supports 5 motors max"
**Solution**: Don't set `N_AXIS > 3`. Use ganged axes (N_AXIS=3 + 2 ganged motors = 5 total)

**Problem**: Changes to `grblhal_machine_build_flags` not taking effect
**Solution**: Re-run the playbook to regenerate the `[env:kwcnc_yeti]` block, then clean the build cache: `pio run -t clean -e kwcnc_yeti`

### Flash Issues

**Problem**: Board not in DFU mode
**Solution**: Hold BOOT0, press RESET, release BOOT0. Use `lsusb | grep 0483:df11` to verify.

**Problem**: Permission denied on /dev/ttyACM0
**Solution**: Add user to dialout group: `sudo usermod -a -G dialout $USER` (then logout/login)

## Directory Structure

```
grblhal-builder/
├── README.md                                # This file
├── defaults/
│   └── main.yml                             # Default variables
├── tasks/
│   └── main.yml                             # Main tasks
└── templates/
    ├── platformio_kwcnc_yeti.ini.j2          # [env:kwcnc_yeti] build environment
    ├── skr3-build.sh.j2                      # Build script
    └── skr3-flash.sh.j2                      # Flash script
```

## References

- [grblHAL Documentation](https://github.com/grblHAL/core)
- [BTT SKR 3 Documentation](https://github.com/bigtreetech/SKR-3)
- [TMC5160 Datasheet](https://www.trinamic.com/products/integrated-circuits/details/tmc5160/)

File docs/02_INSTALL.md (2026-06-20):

# Base Software Setup

## Pi Installation

### Pi Base OS

Flash the BTT Pi with its official Debian-based 64-bit OS image from the
[BTT-Pi releases page](https://github.com/bigtreetech/BTT-Pi/releases).
Enable SSH during imaging (or via `raspi-config` on first boot) and note the
board's IP address — you'll need it for the Ansible step.

The playbook targets **Debian arm64** and expects to run as `root` over SSH.

### Set Up the Pi

```bash
# Go into the Ansible directory
cd ansible/

# Change this to your Pi's IP or hostname
export PI_IP=192.168.42.42

# May need to tweak root
ansible-playbook -i "${PI_IP}," -u root pi-setup.yml
```

if everything went well, at the end you should get:

```
[...]

TASK [grblhal-builder : Display helper scripts information] **********************************
ok: [192.168.1.46] => {
    "msg": [
        "========================================",
        "grblHAL Build Environment Ready!",
        "========================================",
        "Source directory: /opt/grblhal",
        "Build directory: /opt/grblhal/build",
        "Target board: BTT_SKR_3_EZ",
        "MCU: STM32H7xx",
        "PlatformIO environment: btt_skr_30_h723_tmc5160_bl128",
        "",
        "Helper scripts installed:",
        "  - skr3-build    Build the firmware",
        "  - skr3-flash    Flash the firmware via USB (DFU)",
        "",
        "Usage:",
        "  skr3-build                    # Build firmware",
        "  skr3-flash                    # Flash latest firmware (interactive)",
        "  skr3-flash custom.bin         # Flash specific firmware file",
        "",
        "The flash script will guide you through the DFU bootloader process.",
        "========================================"
    ]
}
```

To run only a subset of roles, use `--tags`. Available tags:

| Tag | Roles covered |
|-----|---|
| `system` | hostname, rsyslog, repos, avahi, nginx |
| `network` | avahi, nginx |
| `apps` | gsender, cnc-console |
| `development` | grblhal-builder |
| `hostname` | hostname |
| `rsyslog` | rsyslog |
| `repos` | repos (custom apt repository) |
| `avahi` | avahi (mDNS) |
| `nginx` | nginx (reverse proxy for gSender) |
| `gsender` | gsender |
| `grblhal` | grblhal-builder |
| `cnc-console` | cnc-console |

Example — re-deploy only the firmware build tools:

```bash
ansible-playbook -i "${PI_IP}," -u root pi-setup.yml --tags grblhal
```

## Building Firmware

Once the Pi is provisioned, SSH into it and run the build script. The grblHAL
sources are deployed to `/opt/grblhal` by Ansible; the compiled binary lands in
`/opt/grblhal/build/`.

### Using the Helper Script

Build can be done with the following script:

```bash
skr3-build
```

You should get an output similar to:

```
[...]
======================================================== 1 succeeded in 00:11:29.833 ========================================================
Build successful!
Firmware: .pio/build/btt_skr_30_h723_tmc5160_bl128/firmware.bin
Firmware copied to: /opt/grblhal/build/firmware_latest.bin

======================================
Build Complete!
======================================
```

Under the hood it uses [PlatformIO](https://platformio.org/) with the custom
`kwcnc_yeti` environment injected into `/opt/grblhal/platformio.ini` by Ansible.
To see every command executed, run `bash -x skr3-build`.

## Flashing Firmware

### Using the Helper Script (Recommended)

```bash
skr3-flash
```

You should get an output similar to:

```
[...]
═══════════════════════════════════════
  Flash Complete! ✓
═══════════════════════════════════════

To start the new firmware:

Press the RESET button on the board
        Press any key after you've pressed RESET...

Waiting for board to restart...
✓ Board is running! (Virtual COM Port detected)
✓ Serial device: /dev/ttyACM0

You can now connect to grblHAL via /dev/ttyACM0
```

The script will guide you through:
1. Entering DFU bootloader mode (interactive, requires you to reset the board in DFU by pushing RESET and BOOT at the same time)
2. Flashing the firmware
3. Resetting the board to run the new firmware

To see every command executed, run `bash -x skr3-flash`.

Once flashed, the board is available on `/dev/ttyACM0` at 115200 baud.

```bash
cnc-console
```

## Configuration Tweaks

```bash
vim /opt/grblhal/platformio.ini
```

And edit the end:

```ini
# BEGIN ANSIBLE MANAGED BLOCK: kwcnc_yeti
# KW CNC Yeti - BTT SKR 3 H743 with TMC5160, ganged XY axes, SPI drivers
[env:kwcnc_yeti]
board = generic_stm32h723vg
board_build.ldscript = STM32H723VGTX_FLASH_BL.ld
build_flags = ${env:btt_skr_30_h723_tmc5160_bl128.build_flags}
  !echo "-D BUILD_INFO='\"KWCNC_$(date +%%Y%%m%%d_%%H%%M)\"'"
  -D X_GANGED=1
  -D X_AUTO_SQUARE=1
  -D Y_GANGED=1
  -D Y_AUTO_SQUARE=1
  -D DEFAULT_X_CURRENT=1000.0f
  -D DEFAULT_Y_CURRENT=1000.0f
  -D DEFAULT_Z_CURRENT=1000.0f
  -D DEFAULT_A_CURRENT=1000.0f
  -D DEFAULT_B_CURRENT=1000.0f
  -D DEFAULT_X_STEPS_PER_MM=80.0f
  -D DEFAULT_Y_STEPS_PER_MM=80.0f
  -D DEFAULT_Z_STEPS_PER_MM=400.0f
  -D DEFAULT_A_STEPS_PER_MM=80.0f
  -D DEFAULT_B_STEPS_PER_MM=80.0f
  -D ESTOP_ENABLE=0
  -D CONTROL_ENABLE=0
  -D TRINAMIC_UART_ENABLE=0
  -D TRINAMIC_SPI_ENABLE=1
  -D TRINAMIC_ENABLE=5160
  -D TRINAMIC_R_SENSE=75
lib_deps = ${env:btt_skr_30_h723_tmc5160_bl128.lib_deps}
lib_extra_dirs = ${env:btt_skr_30_h723_tmc5160_bl128.lib_extra_dirs}
upload_protocol = dfu
# END ANSIBLE MANAGED BLOCK: kwcnc_yeti
```

To make these changes permanent, update the `grblhal_machine_build_flags` list
in the `vars:` section of `ansible/pi-setup.yml` and re-run the playbook with
`--tags grblhal` to redeploy the `platformio.ini` block.

## Connect to gSender

From there, if you are on the same network, you should be able to connect with the following URL: https://kwcnc.local (accept self-signed cert).

Once connected you should be able to control the CNC or run gcode.

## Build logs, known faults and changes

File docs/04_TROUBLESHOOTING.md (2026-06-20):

# Troubleshooting & Gotchas

## Connecting to the Pi

The setup is network accessible. Join the Pi to a WiFi network, or plug it into an Ethernet network with DHCP
(see `misc/pi-dhcp-nat.sh` to temporarily turn your laptop into a router if needed).

Once on the same LAN, the Pi is reachable via mDNS at `kwcnc.local`:

| Service | Address |
|---|---|
| SSH | `ssh root@kwcnc.local` |
| gSender UI | http://kwcnc.local |

### Joining a WiFi Network

```shell
nmtui
```

---

## Interacting with the CNC (gCode)

### Serial Console

Two equivalent ways to open an interactive gCode console:

```shell
cnc-console                  # convenience wrapper
screen /dev/ttyACM0 115200   # equivalent manual command
```

The board is on `/dev/ttyACM0` at 115200 baud. There is also a built-in (tiny) console in the bottom-right of gSender.

### Useful Diagnostic Commands

| Command | Purpose |
|---|---|
| `$$` | List all settings |
| `$I` | Show firmware/system info |
| `?` | Show current status |
| `$RST=*`  | Reset all settings to factory |
| `$HELP` | List help topics |
| `M122` | Trinamic driver status |
| `$338` | Driver settings bitmask |

### Command Examples

```bash
> $$      # List all settings
$0=5.0
$1=25
$2=0
$3=0
$4=7
[...]
ok
```

```bash
> $I      # Show system info
[VER:1.1f.20260520:KWCNC_20260616_2107]
[OPT:VNMSL2,100,1024,3,0]
[AXS:3:XYZ]
[NEWOPT:ENUMS,RT+,TC,SED,FS,TMC=7,SD]
[FIRMWARE:grblHAL]
[SIGNALS:P]
[NVS STORAGE:*FLASH 32K]
[FREE MEMORY:201K]
[DRIVER:STM32H723@480MHz]
[DRIVER VERSION:260517]
[BOARD:BTT SKR-3]
[AUX IO:4,2,0,0]
[PLUGIN:Bootloader Entry v0.02]
[PLUGIN:FS stream v1.11]
[PLUGIN:FS macro plugin v0.23]
[PLUGIN:Trinamic v0.33]
[PLUGIN:SDCARD v1.27]
ok
```

```bash
> ?       # Show status
<Idle|MPos:0.000,0.000,0.000|Bf:100,1024|FS:0,0|Pn:XYZP|Ov:100,100,100>
```

```bash
> $RST=*  # Reset every setting to factory
[MSG:Restoring defaults]
```

```bash
> $HELP   # halp!
Help topics:
 Commands
 Settings
 Aux ports
[...]
ok
```

```bash
> M122    # Trinamic Driver Status
[TRINAMIC]
                      X       Y       Z      X2      Y2
Driver          TMC5160 TMC5160 TMC5160 TMC5160 TMC5160
Set current        1000    1000    1000    1000    1000
RMS current         990     990     990     990     990
Peak current       1400    1400    1400    1400    1400
Run current       19/31   19/31   19/31   19/31   19/31
[...]
ok
```

```bash
> $338    # driver settings bitmask
$338=7
ok
```

---

## Current Settings

### Motor Current (mA)

```bash
$140=1200    # X axis current (mA)
$141=1200    # Y axis current
$142=1200    # Z axis current
$143=1200    # M3 axis current
$144=1200    # M4 axis current
```

### Steps per mm

```bash
$100=80.0    # X steps/mm
$101=53.33   # Y steps/mm (calibrated: 80 × 100/150)
$102=266.67  # Z steps/mm (calibrated: 400 × 100/150)
$103=80.0    # X2 steps/mm (ganged, same as X)
$104=53.33   # Y2 steps/mm (ganged, same as Y)
```

---

## Gotchas

* If you have even just one missing driver, SPI control stops working (M122 returns `[MSG:Warning: Could not communicate with stepper driver!]` error). The drivers could actually be run without SPI... and some random current settings (smoky-smocky!).
* Settings are kind of stored on flash, including stuff like `BUILD_INFO`. A reset from time to time might be a good idea.
* For this setup, don't use `my_machine.h`. Only leverage `-D PARAM=VALUE` in platformio.
* grblHAL documentation is a bit lacking.
* Bodge wires are the devil (I might have or have not burnt a board).

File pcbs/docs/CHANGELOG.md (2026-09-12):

# Design changelog

Append-only, newest first. One entry per committed copperhead run.

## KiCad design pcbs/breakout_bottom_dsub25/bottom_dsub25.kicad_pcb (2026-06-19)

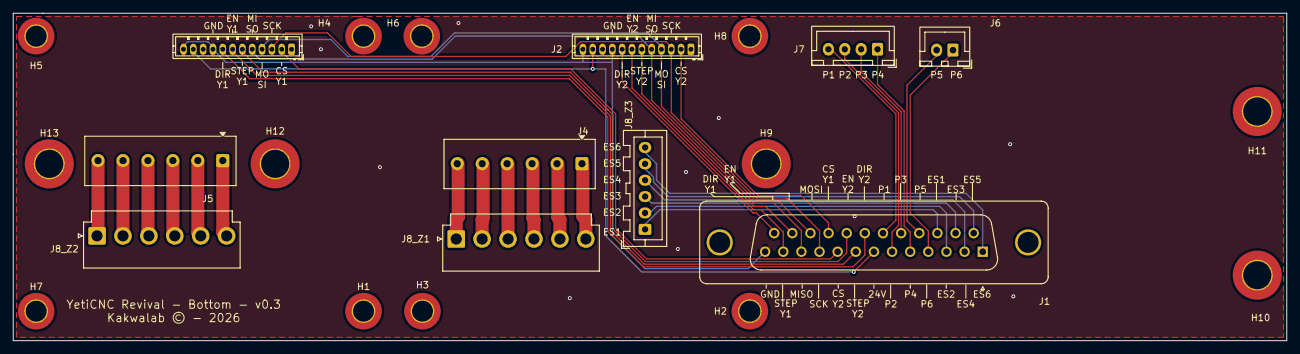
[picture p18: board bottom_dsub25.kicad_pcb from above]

Board: 2 copper layers, 194.5 x 50.0 mm, 23 parts (0 on the bottom side), 37 nets.

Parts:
H1, H2, H3, H4, H5, H6, H7, H8: MountingHole; MountingHole_3.2mm_M3_DIN965_Pad_TopBottom
H9, H10, H11, H12, H13: MountingHole; MountingHole_4.3mm_M4_DIN965_Pad_TopBottom
J1: DB25_Pins; DSUB-25_Pins_Vertical_P2.77x2.84mm_MountingHoles
J2, J3: Conn_01x12; JST_ZH_B12B-ZR_1x12_P1.50mm_Vertical
J4, J5: Screw_Terminal_01x06; TerminalBlock_Phoenix_MKDS-1-6-3.81_1x06_P3.81mm_Horizontal
J6: Conn_01x02; JST_XH_B2B-XH-A_1x02_P2.50mm_Vertical
J7: Conn_01x04; JST_XH_B4B-XH-A_1x04_P2.50mm_Vertical
J8_Z1, J8_Z2: Conn_01x06_Pin; JST_VH_B6P-VH_1x06_P3.96mm_Vertical
J8_Z3: Conn_01x06_Pin; JST_XA_B06B-XASK-1_1x06_P2.50mm_Vertical

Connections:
GND: J1.13, J2.9, J2.12, J3.9, J3.12
unnamed: J1.14, J8_Z3.5
unnamed: J1.15, J8_Z3.3
unnamed: J1.16, J8_Z3.1
unnamed: J1.17, J6.2
unnamed: J1.18, J7.2
unnamed: J1.19, J7.4
unnamed: J1.20, J3.8
unnamed: J1.21, J3.6
unnamed: J1.22, J2.2
unnamed: J1.23, J2.4, J3.4
unnamed: J1.24, J2.6
unnamed: J1.25, J2.8
unnamed: J1.10, J2.3, J3.3
unnamed: J1.11, J2.5, J3.5
unnamed: J1.12, J2.7
unnamed: J1.7, J2.11, J3.11
unnamed: J1.9, J3.2
unnamed: J1.8, J3.7
unnamed: J4.1, J8_Z1.6
unnamed: J4.2, J8_Z1.5
unnamed: J4.3, J8_Z1.4
unnamed: J4.4, J8_Z1.3
unnamed: J4.5, J8_Z1.2
unnamed: J4.6, J8_Z1.1
unnamed: J5.1, J8_Z2.6
unnamed: J5.2, J8_Z2.5
unnamed: J5.3, J8_Z2.4
unnamed: J5.4, J8_Z2.3
unnamed: J5.5, J8_Z2.2
unnamed: J5.6, J8_Z2.1
unnamed: J1.4, J6.1
unnamed: J1.5, J7.1
unnamed: J1.6, J7.3
unnamed: J1.3, J8_Z3.2
unnamed: J1.2, J8_Z3.4
unnamed: J1.1, J8_Z3.6

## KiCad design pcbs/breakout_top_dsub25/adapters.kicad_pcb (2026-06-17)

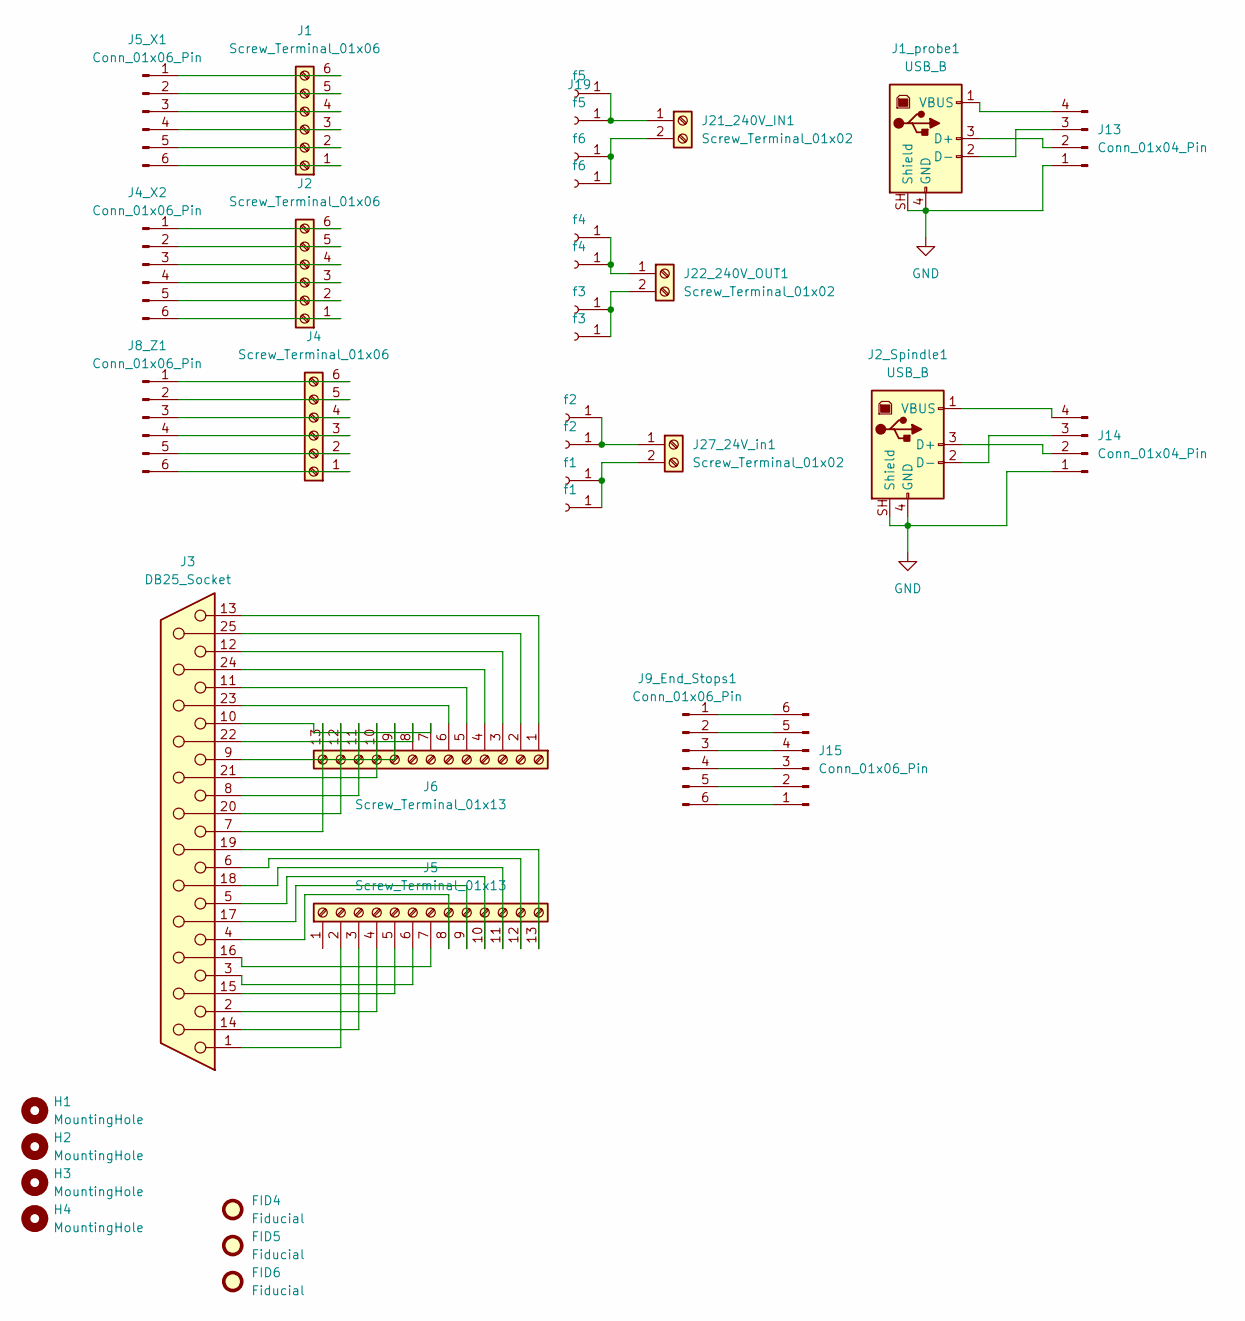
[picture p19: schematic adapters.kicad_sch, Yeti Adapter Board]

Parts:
F5: f5; SolderWire-1.5sqmm_1x01_D1.7mm_OD3mm
FID4, FID5, FID6: Fiducial; Fiducial_0.5mm_Mask2mm
H1, H2, H3, H4: MountingHole; MountingHole_3.2mm_M3_Pad_TopBottom
J1, J2, J4: Screw_Terminal_01x06; TerminalBlock_Phoenix_MKDS-1-6-3.81_1x06_P3.81mm_Horizontal
J1_probe1, J2_Spindle1: USB_B; USB_B_Lumberg_2411_02_Horizontal
J3: DB25_Socket; DSUB-25_Socket_Horizontal_P2.77x2.54mm_EdgePinOffset9.40mm
J4_X2, J5_X1: Conn_01x06_Pin; JST_VH_S6P-VH_1x06_P3.96mm_Horizontal
J5, J6: Screw_Terminal_01x13; TerminalBlock_Phoenix_MKDS-1-13-3.81_1x13_P3.81mm_Horizontal
J8_Z1, J9_End_Stops1: Conn_01x06_Pin; JST_XA_S06B-XASK-1N-BN_1x06_P2.50mm_Horizontal
J10, J11: f3; SolderWire-1.5sqmm_1x01_D1.7mm_OD3mm
J12, J16: f4; SolderWire-1.5sqmm_1x01_D1.7mm_OD3mm
J13, J14: Conn_01x04_Pin; JST_XH_B4B-XH-A_1x04_P2.50mm_Vertical
J15: Conn_01x06_Pin; JST_XH_B6B-XH-A_1x06_P2.50mm_Vertical
J17, J18: f6; SolderWire-1.5sqmm_1x01_D1.7mm_OD3mm
J19: f5; SolderWire-1.5sqmm_1x01_D1.7mm_OD3mm
J21_240V_IN1, J22_240V_OUT1, J27_24V_in1: Screw_Terminal_01x02; TerminalBlock_Phoenix_MKDS-1,5-2_1x02_P5.00mm_Horizontal
J23, J24: f2; SolderWire-1.5sqmm_1x01_D1.7mm_OD3mm
J25, J26: f1; SolderWire-1.5sqmm_1x01_D1.7mm_OD3mm

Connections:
GND: J1_probe1.4 (GND), J1_probe1.SH (Shield), J2_Spindle1.4 (GND), J2_Spindle1.SH (Shield), J13.1, J14.1
unnamed: F5.1 (Pin_1_1), J19.1 (Pin_1_1), J21_240V_IN1.1
unnamed: J1.1, J5_X1.6
unnamed: J1.2, J5_X1.5
unnamed: J1.3, J5_X1.4
unnamed: J1.4, J5_X1.3
unnamed: J1.5, J5_X1.2
unnamed: J1.6, J5_X1.1
unnamed: J2.1, J4_X2.6
unnamed: J2.2, J4_X2.5
unnamed: J2.3, J4_X2.4
unnamed: J2.4, J4_X2.3
unnamed: J2.5, J4_X2.2
unnamed: J2.6, J4_X2.1
unnamed: J3.14, J5.3
unnamed: J3.15, J5.5
unnamed: J3.16, J5.7
unnamed: J3.17, J5.9
unnamed: J3.18, J5.11
unnamed: J3.19, J5.13
unnamed: J3.20, J6.12
unnamed: J3.21, J6.10
unnamed: J3.22, J6.8
unnamed: J3.23, J6.6
unnamed: J3.24, J6.4
unnamed: J3.25, J6.2
unnamed: J4.1, J8_Z1.6
unnamed: J4.2, J8_Z1.5
unnamed: J4.3, J8_Z1.4
unnamed: J4.4, J8_Z1.3
unnamed: J4.5, J8_Z1.2
unnamed: J4.6, J8_Z1.1
unnamed: J3.1, J5.2
unnamed: J3.2, J5.4
unnamed: J3.3, J5.6
unnamed: J3.4, J5.8
unnamed: J3.5, J5.10
unnamed: J3.6, J5.12
unnamed: J3.13, J6.1
unnamed: J3.12, J6.3
unnamed: J3.11, J6.5
unnamed: J3.10, J6.7
unnamed: J3.9, J6.9
unnamed: J3.8, J6.11
unnamed: J3.7, J6.13
unnamed: J10.1 (Pin_1_1), J11.1 (Pin_1_1), J22_240V_OUT1.2
unnamed: J12.1 (Pin_1_1), J16.1 (Pin_1_1), J22_240V_OUT1.1
unnamed: J1_probe1.3 (D+), J13.2
unnamed: J1_probe1.2 (D-), J13.3
unnamed: J1_probe1.1 (VBUS), J13.4
unnamed: J2_Spindle1.3 (D+), J14.2
unnamed: J2_Spindle1.2 (D-), J14.3
unnamed: J2_Spindle1.1 (VBUS), J14.4
unnamed: J9_End_Stops1.6, J15.1
unnamed: J9_End_Stops1.5, J15.2
unnamed: J9_End_Stops1.4, J15.3
unnamed: J9_End_Stops1.3, J15.4
unnamed: J9_End_Stops1.2, J15.5
unnamed: J9_End_Stops1.1, J15.6
unnamed: J17.1 (Pin_1_1), J18.1 (Pin_1_1), J21_240V_IN1.2
unnamed: J23.1 (Pin_1_1), J24.1 (Pin_1_1), J27_24V_in1.1
unnamed: J25.1 (Pin_1_1), J26.1 (Pin_1_1), J27_24V_in1.2

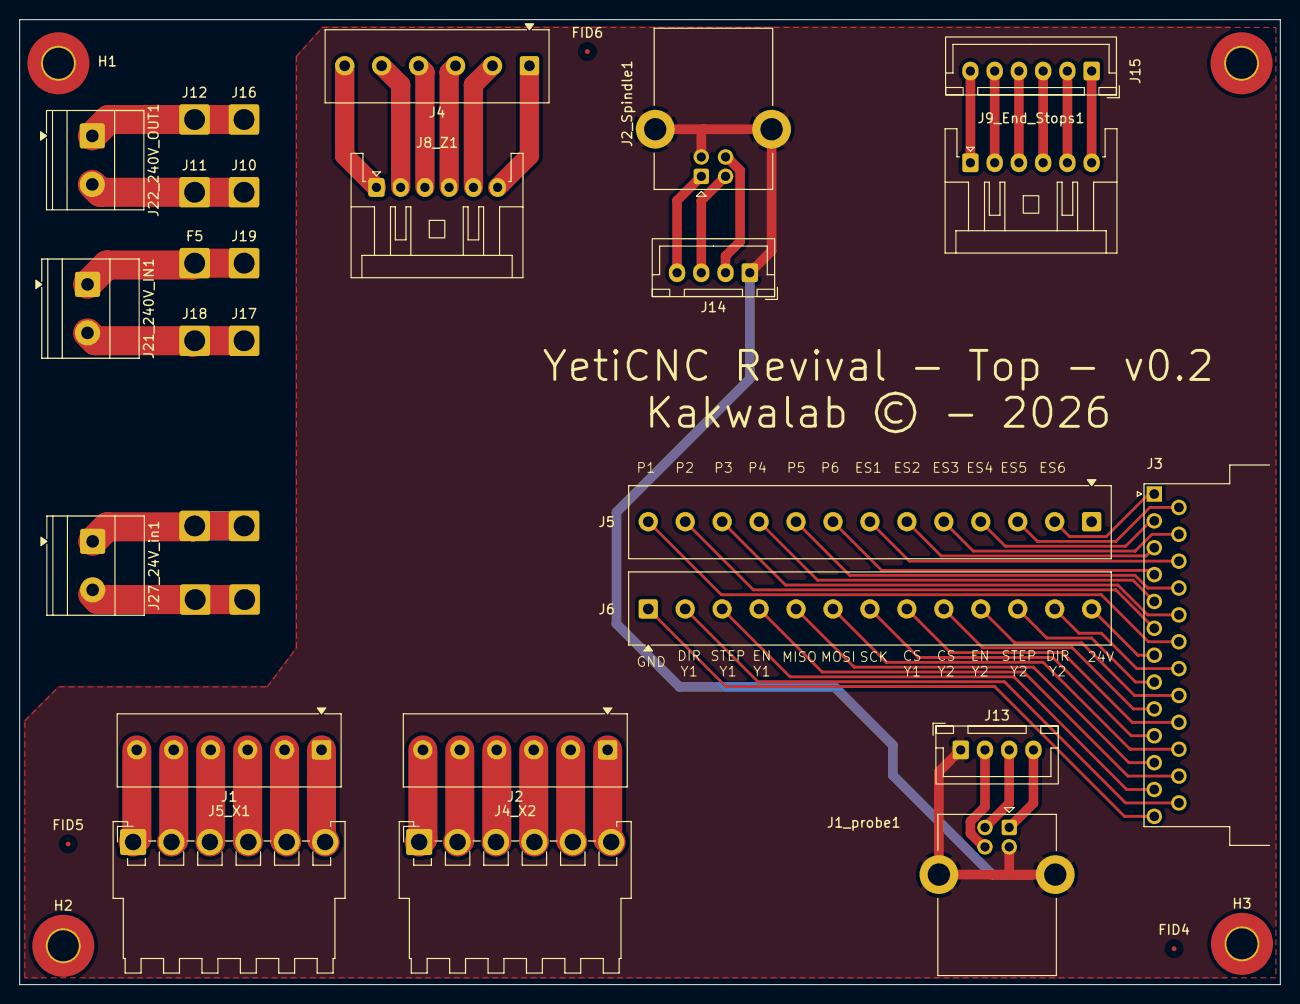
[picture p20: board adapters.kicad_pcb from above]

Board: 2 copper layers, 130.0 x 99.5 mm, 37 parts (0 on the bottom side), 62 nets.

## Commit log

2026-01-17 switch to xwayland-run
2026-01-23 grblhal submodule for STM32H7
2026-01-23 adding role to setup build tools for grblhal
2026-01-28 update grblhal
2026-01-31 switch to everything defined in my_machine.h
2026-01-31 Configure grblHAL for maximum torque at 2.5A
    - Set motor current to 2.5A (2500mA) for all axes
    - Reduce microstepping to 8 for 2x torque per step
    - Increase hold current to 75% for better holding torque
    - Keep SpreadCycle mode for maximum torque delivery
    - Fix platformio.ini: add platform=ststm32 and HAL driver paths
    - Add comprehensive README for grblhal-builder role
2026-03-17 Fix grblhal-builder role: use ansible_facts instead of deprecated ansible_architecture
    Made-with: Cursor
2026-03-17 Fix grblhal-builder defaults: use ansible_facts instead of deprecated ansible_user_id
    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
2026-03-17 Fix grblhal-builder: set build user/group to root explicitly
    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
2026-03-17 Fix grblhal-builder: allow platformio.ini to be copied so it can be patched
    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
2026-03-18 skeleton for the wiring
2026-03-20 Add board labels and remove MAX switchs limits
2026-04-14 adding skeleton for pcb
    [adapters.kicad_pcb, adapters.kicad_sch]
2026-04-29 PCB draft tweaks + ignores
    [adapters.kicad_sch]
2026-04-30 first rough version of top board
    [adapters.kicad_pcb, adapters.kicad_sch]
2026-05-01 adding a dsub 25 variant + tweaks
    [adapters.kicad_pcb, adapters.kicad_sch]
2026-05-03 adding project for bottom page
    [bottom_dsub25.kicad_pcb, bottom_dsub25.kicad_sch]
2026-05-07 progress on the bottom board (most connectors, etc)
    [bottom_dsub25.kicad_pcb, bottom_dsub25.kicad_sch]
2026-05-09 rough component positioning for bottom pcb + add connectors
    [bottom_dsub25.kicad_pcb, bottom_dsub25.kicad_sch]
2026-05-09 add routinng
    [bottom_dsub25.kicad_pcb, bottom_dsub25.kicad_sch]
2026-05-10 adding various silk layer labels
    [adapters.kicad_pcb, bottom_dsub25.kicad_pcb, bottom_dsub25.kicad_sch]
2026-05-10 tweak top board
    add mounting holes in the middle (enable zip for cables?)
    reposition a few components
    fix some rules warnings
    [adapters.kicad_pcb]
2026-05-10 adding ground plan
    [adapters.kicad_pcb, bottom_dsub25.kicad_pcb]
2026-05-10 add version/name
    [adapters.kicad_pcb, bottom_dsub25.kicad_pcb]
2026-06-04 adding stands cad model
    [standoff_driver_bottom.FCStd]
2026-06-04 increase size of standoff
    [standoff_driver_bottom.FCStd]
2026-06-10 4mm diameter for the stand legs of the driver mounts
    [standoff_driver_bottom.FCStd]
2026-06-10 adding backplate for bottom PCB
    [backplate_bottom.FCStd]
2026-06-13 lower current
2026-06-15 creating a dedicated plateform.io section for our machine
2026-06-16 switch to the correct board
2026-06-16 fix board CPU
2026-06-16 more options to try to force SPI
2026-06-17 Revise limit switch port mapping in 01_HARDWARE.md
    Updated limit switch port mapping table in hardware documentation.
2026-06-17 adding bottom backplate
    [backplate_bottom.FCStd]
2026-06-17 remove the vga project
    [adapters.kicad_pcb, adapters.kicad_sch]
2026-06-17 wire-in the 24V from the main board + wire ground on this pin
    [bottom_dsub25.kicad_pcb, bottom_dsub25.kicad_sch]
2026-06-17 relabel dsub 25 pins which were rewired/renumbered for 24V routing + add spacing for power supply stuff.
    [adapters.kicad_pcb, adapters.kicad_sch]
2026-06-19 bottom PCBs, correct hole placement + grounded plane + remove warnings
    [bottom_dsub25.kicad_pcb]
2026-06-19 reorg of cad stuff + add drag chain links
    [backplate_bottom.FCStd, chain_link_v2-clip.scad, chain_link_v2-clip.stl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]
2026-06-19 adding drag chain
2026-06-19 adding the ends for the drag chains
    [end1-Body.stl, end2-Body.stl]
2026-06-20 rought draft of the wiring schemas
2026-06-20 docs: clean up 01_HARDWARE.md — fix typos, grammar, and TODO links
    Resolve broken TODO placeholders with real relative links to the
    grblHAL board map header and drag chain CAD files. Fix several
    grammar/typo issues throughout.
2026-06-20 adding warning for stepper mirrored
2026-06-20 docs: fix typos, grammar, and broken markdown across multiple files
    - 00_INTRO.md: fix "our of reach", "lastis", "let→leave", "stepped-up", "syndrom", stray escapes
    - 02_INSTALL.md: fix bare lines rendering as headings, broken sentence after flash step, "Setup→Set Up", remove trailing colon from heading
    - 03_CONFIGURATION.md: fix "Tunning→Tuning"
    - 90_MISC.md: fix accidental h1 heading, "SDCard→SD Card", duplicate heading, "ou→You" typo in comment
2026-06-20 tweaks for the configuration and calibration
2026-06-22 adding some comments
    [chain_link_v2-clip.scad]
2026-06-22 clean-up options
    [chain_link_v2-clip.scad]
2026-06-22 switch to 4 spaces indent + tweak shape
    tweaks:
    * 45 angles
    * rounded base
    * tighter tolerances
    [chain_link_v2-clip.scad, chain_link_v2-clip.stl]
2026-06-22 adding flags for the legs
    [chain_link_v2-clip.scad]
2026-06-22 add support for legs
    [chain_link_v2-clip.scad, end1-Body.stl]
2026-06-22 switch back to not rounding stuff (otherwise, chain flex too much on the other side)
    [chain_link_v2-clip.scad, chain_link_v2-clip.stl, end1-Body.stl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]
2026-06-22 remove now useless freecad end chain
2026-06-22 better names for the stl files
    [end1.stl, end3.stl, middle.stl]
2026-06-22 adding tolerances for the clip
    [chain_link_v2-clip.scad]
2026-06-22 add makefiles and clean-up stls
    [chain_link_inner_leg.stl, chain_link_no_leg.stl, chain_link_outter_leg.stl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]
2026-09-10 adding estop bracket mount (cut-out provisional)
    [estop_bracket.FCStd]
2026-09-14 tweaking estop bracket
    [estop_bracket.FCStd]
2026-10-08 adding covers
    [cap.FCStd, cover.FCStd]
2026-10-09 update cap for PSU connectors
    [cap-BodyPad004.stl, cap.FCStd]
